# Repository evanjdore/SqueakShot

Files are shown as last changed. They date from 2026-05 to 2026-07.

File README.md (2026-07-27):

<p align="center">
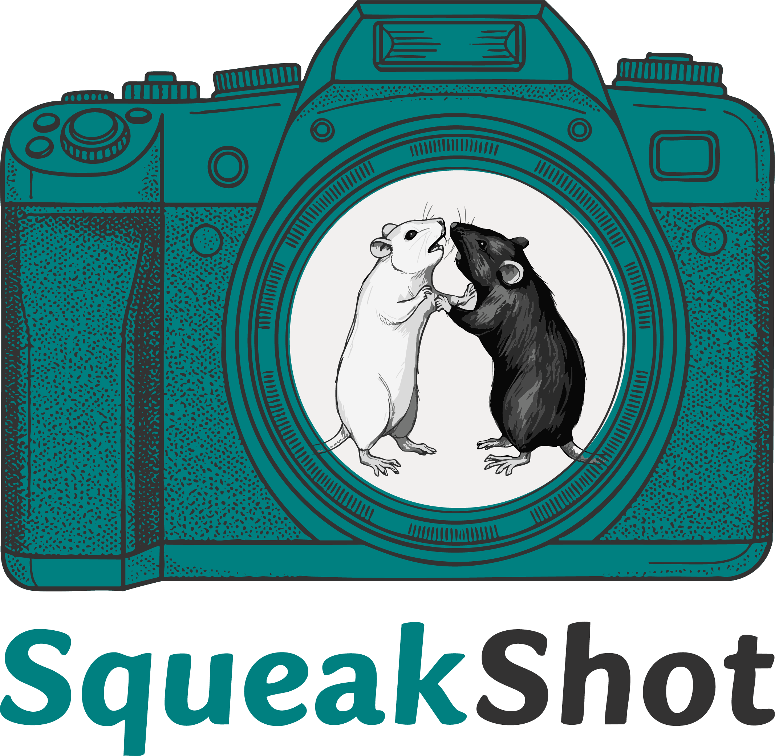
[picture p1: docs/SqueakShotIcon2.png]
SqueakShot
  
</p>

# SqueakShot

Synchronized multi-camera video recording for the Raspberry Pi, built for
behavioral neuroscience experiments (rodent vocalization + behavior, hence the
name) where several camera angles of the same animal must line up
frame-for-frame.

A set of Raspberry Pi 4 / 5 units — one *server* plus any number of *clients* —
record H.264 video with per-frame microsecond timestamps, all starting at the
same wall-clock instant. A desktop controller (a small Flask web app, currently
**v9.2.5**) drives the whole workflow from one browser UI: previewing,
recording, pulling footage off the Pis, encoding to MP4, frame-matching the
cameras to each other, and trimming to the behavior window.

## What it does

The full pipeline, all from `http://localhost:5000`:

1. **Record** — Enter an animal ID and project ID and hit *Start Recording*.
   Every Pi opens its encoder at the same scheduled moment (see
   [synchronization](#how-synchronization-works)). Footage lands on each Pi's
   SD card as a `.h264` file plus a `.pts` sidecar of per-frame timestamps.
2. **Preview** — Live MJPEG streams from every camera for framing and focus.
   Mutually exclusive with recording, since the cameras can't be shared.
3. **Encode** — Download the raw footage from every Pi in parallel and encode
   each camera to MP4.
4. **Sync** — Analyze the `.pts` files, match frames across all cameras to
   within a 20 ms tolerance, and write per-camera *synced* MP4s that begin on
   the same frame.
5. **Trim** — Scrub to the start and end of the behavior bout on a frame
   preview, then clip every camera together to that exact range.

Pre-flight checks (clock skew and free disk on each Pi), live thermal and
throttling status per camera, and an in-GUI settings deploy round it out.

## What's new

- **v9.2.5 (current)** — `.pts` sidecars are now written reliably on the Pi 5
  via a `TimestampingFileOutput` subclass, since `picamera2`'s
  `start_encoder(pts=...)` is silently ignored on the libav code path. Also
  ships a runtime monkey-patch for the `picamera2` + PyAV ≥14 incompatibility
  (`pict_type` must be an int, not the string `"I"`) that otherwise crashes
  the encoder on newer images. Quiets the bogus "force_key_frame unsupported"
  log line.
- **v9.2** — Fixes 0-byte `.h264` recordings on the Pi 5, an installer bug
  that deployed only the first camera, and server-side control-socket races.
  Adds `SQUEAKSHOT_PORT` and `SQUEAKSHOT_PREFLIGHT_CLOCK_SKEW_MS` environment
  variables (the former dodges macOS AirPlay on port 5000). Full detail in
  [CHANGELOG.md](CHANGELOG.md).
- **Isolated install** — The desktop controller installs into a conda/mamba
  environment (`environment.yml`) that also bundles FFmpeg, so nothing touches
  your system Python and there is no separate FFmpeg download.
- **Deploy settings from the GUI** — The Settings tab can push camera
  resolution/fps/bitrate to every Pi and restart the record service, instead
  of re-running `install.sh`.
- Inline pre-flight results, per-camera preview reload, parallel encode /
  sync / trim, and assorted bug fixes (see `CHANGELOG.md`).

## Hardware

- Two or more Raspberry Pi 4 / 5 running Raspberry Pi OS Bookworm (64-bit)
- A Camera Module 3 (IMX708, Wide variant recommended) on each Pi
- Wired Ethernet between every Pi and the desktop running the controller
  (Wi-Fi works but degrades preview latency and pre-flight clock-skew margin)
- A desktop (Windows / macOS / Linux) for the controller — modest CPU is fine,
  the heavy lifting is FFmpeg encode/sync on a small number of camera streams

For the reference physical rig — a 3D-printed three-camera enclosure built
around a single mouse cage — see the **[hardware build guide](BUILD.md)**. It
covers the full bill of materials, dimensions, wiring, and assembly, and the
printable `.3mf` / editable `.f3d` files live in [`hardware/`](hardware/).

## Installation

See [INSTALL.md](INSTALL.md) for the full walkthrough. The short version:

### Prerequisites

**On each Raspberry Pi** — Raspberry Pi OS Bookworm (64-bit), a working Camera
Module 3, SSH enabled, and `python3-picamera2` + `python3-av` installed (both
ship on standard Bookworm images). On the Pi 5 specifically, `python3-av` is
not optional — without it the recorder falls back to the V4L2 H.264 path,
which has produced 0-byte `.h264` files on some libcamera builds.

**On the desktop** — conda or mamba (recommended, e.g. via Miniforge). The
controller's Python, Flask, NumPy, and FFmpeg all come from the
`environment.yml` conda environment. Without conda you instead need Python
3.10+ and FFmpeg/FFprobe on `PATH` yourself (the launcher will pip-install
Flask + NumPy in that case).

You also need passwordless SSH from the desktop to every Pi
(`ssh-copy-id user@pi-ip`) and the Pis on NTP / chrony so their wall clocks
agree to within ~100 ms (pre-flight check enforces this).

### 1. Configure

```bash
./setup.sh                   # setup.bat on Windows
```

Interactively asks for each camera's name / IP / SSH user, the video
directories, and the resolution / fps / bitrate, then writes
`controller/camera_config.json`.

### 2. Deploy to the Pis

```bash
cd pi-deploy && ./install.sh
```

Copies the capture scripts and a generated `camera_settings.json` to every Pi,
installs the `squeakshot-record` and `squeakshot-preview` systemd services,
and grants passwordless `systemctl` for just those two units.

### 3. Launch the controller

```bash
cd .. && ./SqueakShot.sh     # SqueakShot.bat on Windows
```

On the first run this builds the `squeakshot` conda environment from
`environment.yml` (a minute or two); later runs reuse it. If conda/mamba is
not found, it falls back to installing Flask + NumPy with `pip`. Then open
<http://localhost:5000>.

To build the environment yourself ahead of time:

```bash
conda env create -f environment.yml      # or: mamba env create -f environment.yml
```

For day-to-day use after install, see [QUICKSTART.md](QUICKSTART.md).

## Architecture

```
                          ┌─────────────────────┐
                          │   Desktop Controller │
                          │  (Flask, port 5000)  │
                          └──────────┬──────────┘
                                     │ TCP 5006 (control)
                                     │ HTTP 8080 (preview)
                                     │ SSH (deploy / systemctl)
                                     ▼
                          ┌──────────────────────┐
                          │  cam0 (server, Pi)   │◄─── records
                          │  port 5005 ─ clients │
                          │  port 5006 ─ control │
                          │  port 8080 ─ preview │
                          └──┬───────────────┬───┘
                             │ TCP 5005      │
                             ▼               ▼
                       ┌──────────┐     ┌──────────┐
                       │   cam1   │     │   cam2   │
                       │  client  │     │  client  │
                       └──────────┘     └──────────┘
```

The controller never talks to client cameras directly: it sends one control
command to the server (cam0), which fans it out to every client. Clients
identify themselves to the server with a `HELLO:<name>` handshake, so cameras
are matched by name rather than connection order.

## How synchronization works

All cameras share a wall-clock reference, so keep the Pis on NTP / chrony. On
*Start Recording* the server schedules a precise start time about 3 seconds in
the future, sends it to every client, waits for ACKs, then everyone busy-waits
to that exact instant before opening their encoder. The `.pts` sidecar next to
each `.h264` records a microsecond timestamp per frame (written by
`TimestampingFileOutput`, a `FileOutput` subclass — `picamera2`'s built-in
`pts=` kwarg is silently ignored on the libav path used by the Pi 5). The
Sync stage uses those timestamps to match frames across cameras offline,
within a 20 ms tolerance.

Heartbeats keep the cluster honest: the server sends `PING` every 10 s during
recording; any client that hears nothing for 30 s auto-stops, so a crashed
server doesn't quietly fill SD cards.

The pre-flight check flags any Pi whose clock is off by more than ~100 ms
(tunable via `SQUEAKSHOT_PREFLIGHT_CLOCK_SKEW_MS`), since skew directly
degrades sync quality.

## Output

- **Raw on Pi**: `~/camera_videos/<camN>_<animal>_<project>.{h264,pts}`
- **Raw pulled to desktop**: `~/SqueakShot_Videos/raw/*.{h264,pts}`
- **Encoded locally**: `~/SqueakShot_Videos/encoded/*.mp4`
- **Synced** (frame-matched across cameras): `~/SqueakShot_Videos/synced/*.mp4`
- **Trimmed** (final clipped clips): `~/SqueakShot_Videos/trimmed/*.mp4`

## Settings that matter

- `output_width` × `output_height`: actual recorded resolution (default 1536×864)
- `sensor_width` × `sensor_height`: leave at 2304×1296 to keep full lens FOV
- `framerate`: 56 fps is the maximum for the binned 2304×1296 sensor mode
  on the IMX708
- `bitrate_mbps`: 25 is plenty for 1536×864; raise for full-res

The ISP downscale trick: the camera reads the same 2304×1296 binned sensor
mode (full FOV) regardless of `output_width`/`output_height`, and the IMX708
ISP scales down before the encoder sees it. So lowering `output_*` reduces
encoder load and bandwidth, but keeps the lens view.

Changing these in the **Settings** tab updates the controller's config; click
**Deploy to Pis** there to copy them to every camera and restart the record
service so they take effect. This is the same operation as re-running
`pi-deploy/install.sh`, but in-place from the GUI.

## Files

```
SqueakShot/
├── SqueakShot.sh / .bat / .command   # launchers
├── setup.sh / .bat                   # interactive config
├── environment.yml                   # conda/mamba env for the controller
├── controller/
│   ├── camera_controller.py          # Flask app
│   ├── sync_lib.py                   # shared N-camera frame-matching algorithm
│   ├── camera_config.example.json    # template config
│   ├── requirements.txt              # pip fallback deps
│   └── templates/controller.html     # web UI
├── pi-deploy/
│   ├── sync_capture.py               # capture service (multi-client server / client)
│   ├── camera_preview.py             # MJPEG preview server
│   ├── install.sh                    # deploys to every camera in config
│   ├── README.md                     # Pi-side files reference + manual deploy notes
│   └── services/
│       ├── squeakshot-record.service.template
│       └── squeakshot-preview.service.template
├── tools/
│   └── sync_videos.py                # standalone offline sync tool (GUI + CLI)
│                                     # — usable without the controller, e.g. for
│                                     # post-hoc resync of older recordings
├── hardware/                         # 3D-print + CAD files for the physical rig
│   ├── print/                        # print-ready .3mf (housing + Pi case)
│   ├── cad/                          # editable Fusion 360 .f3d sources
│   └── README.md                     # hardware file index
├── docs/
│   ├── SqueakShotIcon2.png           # project logo (README header + controller UI)
│   └── images/                       # build-guide renders
├── BUILD.md                          # hardware build guide (BOM, dimensions, assembly)
├── INSTALL.md                        # full installation walkthrough
├── QUICKSTART.md                     # day-to-day usage
├── DEPLOYMENT_HISTORY.md             # field notes
├── CHANGELOG.md
└── README.md
```

## Troubleshooting

**Cameras show as offline.** Check that `ssh user@ip` from your desktop works
without a password (set up keys with `ssh-copy-id`).

**Preview shows "not active".** The record service blocks the camera. Click
"Start Previews" on the Preview tab — it stops the record service first.

**Recording errors with "Clients did not ack".** Check that the
`squeakshot-record` service is running on every client Pi:
```bash
ssh user@cam1 'sudo systemctl status squeakshot-record'
```
If it shows "Permission denied" on systemctl from the controller, re-run
`pi-deploy/install.sh` to set up the passwordless sudo rule.

**Sync quality is "Fair" or worse.** Check whether one camera is dropping
frames (compare per-camera frame counts in the analysis output). Common
causes: under-volted Pi (check thermal cards in Recording tab), CPU
throttling, SD card too slow.

**Settings changes don't take effect.** Editing settings in the GUI only
updates the controller's config. Use **Deploy to Pis** on the Settings tab (or
re-run `pi-deploy/install.sh`) to push them to the cameras.

# Lab
This project was funded by the Maiya Lab at LSUHSC New Orleans

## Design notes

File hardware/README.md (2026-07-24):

# Hardware files

3D-printable parts and CAD sources for the SqueakShot recording rig. For the
full build walkthrough (bill of materials, dimensions, assembly, wiring) see
[../BUILD.md](../BUILD.md).

> **Git LFS:** the `.3mf` and `.f3d` files are tracked with
> [Git LFS](https://git-lfs.com). After cloning, run `git lfs install` once and
> `git lfs pull` to download them.

## Print-ready (`.3mf`)

Print in PLA on the Bambu Lab X1-Carbon (or any FDM printer).

| File | Part |
|---|---|
| `print/recording_housing_parts/LeftSide.3mf` | Housing — left side |
| `print/recording_housing_parts/RightSide.3mf` | Housing — right side |
| `print/recording_housing_parts/LeftStand.3mf` | Housing — left stand |
| `print/recording_housing_parts/RightStand.3mf` | Housing — right stand |
| `print/recording_housing_parts/Lid_Housing.3mf` | Housing — lid |
| `print/raspi_case/Case_Supports.3mf` | Pi case body (with print supports) |
| `print/raspi_case/Lid.3mf` | Pi case lid |
| `print/raspi_case/Buttons.3mf` | Pi case buttons |
| `print/RecordingSetup_3DPrint.3mf` | Combined plate of all parts |

## CAD sources (`.f3d`)

Editable Autodesk Fusion 360 files.

| File | Contents |
|---|---|
| `cad/FullSetup.f3d` | Full assembly (housing + cage + cameras + Pis) |
| `cad/RaspiCase.f3d` | Raspberry Pi case assembly |
| `cad/LeftSide.f3d`, `cad/RightSide.f3d` | Housing side panels |
| `cad/LeftStand.f3d`, `cad/RightStand.f3d` | Housing stands |
| `cad/Lid_Recording.f3d` | Housing lid |
| `cad/raspi_case/Case_with_Supports.f3d` | Pi case body |
| `cad/raspi_case/Lid.f3d` | Pi case lid |
| `cad/raspi_case/Buttons.f3d` | Pi case buttons |

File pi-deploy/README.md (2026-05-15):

# pi-deploy

Files that get pushed to each Raspberry Pi.

## Files

| File | Purpose |
|---|---|
| `sync_capture.py` | Main capture service. Server mode for cam0, client mode for cam1+. |
| `camera_preview.py` | MJPEG preview server (port 8080). Mutually exclusive with sync_capture. |
| `services/squeakshot-record.service.template` | systemd unit for the record service. `install.sh` fills in `__USER__` and `__EXEC__`. |
| `services/squeakshot-preview.service.template` | systemd unit for preview. |
| `install.sh` | Deploys everything to all cameras in `../controller/camera_config.json`. |

## How `install.sh` works

For each camera in the config:
1. SCP `sync_capture.py`, `camera_preview.py`, and a Pi-side
   `camera_settings.json` (derived from the controller config's
   `camera_settings` section) to `/home/<user>/`.
2. Substitute placeholders into the service templates:
   - Server: `python3 sync_capture.py server --config ~/camera_settings.json`
   - Client: `python3 sync_capture.py client --server-ip <IP> --name <NAME> --config ~/camera_settings.json`
3. Install both unit files to `/etc/systemd/system/`, reload daemon, enable
   `squeakshot-record` (auto-start on boot). Preview is manual-start only.
4. Drop a sudoers file allowing the user to `sudo systemctl start/stop`
   those two units without a password (the controller calls this over SSH).

The two services declare `Conflicts=` against each other, so starting one
stops the other automatically.

## Manual deployment (advanced)

If `install.sh` doesn't fit your environment, the equivalent manual steps
on one Pi:

```bash
# On the desktop:
scp pi-deploy/sync_capture.py   maiya@cam0:/home/maiya/
scp pi-deploy/camera_preview.py maiya@cam0:/home/maiya/

# Create camera_settings.json on the Pi:
ssh maiya@cam0 'cat > ~/camera_settings.json' <<'EOF'
{
  "output_width": 1536,
  "output_height": 864,
  "sensor_width": 2304,
  "sensor_height": 1296,
  "framerate": 56,
  "bitrate_mbps": 25,
  "video_dir": "/home/maiya/camera_videos"
}
EOF

# Run sync_capture by hand to test:
ssh maiya@cam0 'python3 ~/sync_capture.py server'   # on cam0
ssh maiya@cam1 'python3 ~/sync_capture.py client --server-ip <CAM0-IP> --name cam1'
```

## Settings file (`camera_settings.json` on each Pi)

```json
{
  "output_width": 1536,    // ISP output resolution width
  "output_height": 864,    // ISP output resolution height
  "sensor_width": 2304,    // sensor mode width (preserves FOV)
  "sensor_height": 1296,   // sensor mode height
  "framerate": 56,         // locked framerate (FrameDurationLimits)
  "bitrate_mbps": 25,      // H.264 bitrate
  "video_dir": "/home/maiya/camera_videos"
}
```

The sensor mode at 2304×1296 is the full-FOV 2×2-binned mode for the IMX708
(Camera Module 3). Lowering `output_*` reduces encoder load and bandwidth
without affecting the lens field of view.

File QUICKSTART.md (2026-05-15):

# Quick Start

Daily use, assuming everything is installed and configured.

## Recording

1. Power on all Pis. The `squeakshot-record` service starts automatically.
2. Launch the controller: `./SqueakShot.sh` (or `SqueakShot.bat`).
3. Open <http://localhost:5000>.
4. Make sure all cameras show **Online**.
5. Recording tab → enter Animal ID and Project ID → **Start Recording**.
6. **Stop Recording** when done.

## Post-processing

After a session, on the Encode tab:

1. Select your recording from the dropdown.
2. **Download from Pis**.
3. Once downloaded, select it under Step 2 and click **Start Encoding**.
4. Switch to the Sync tab, select the same recording, click **Analyze**.
   If sync quality is Good or Excellent, click **Start Synchronization**.
5. Switch to the Trim tab if you want to clip the behavior window.

## Preview (no recording)

Preview tab → **Start Previews** → live MJPEG from each Pi.

To go back to recording: **Stop Previews** → Recording tab → record as normal.

## Files

Default locations on the controller:

```
~/SqueakShot_Videos/
├── raw/        # H.264 + PTS pulled from Pis
├── encoded/    # MP4 + PTS
├── synced/     # frame-matched MP4s
└── trimmed/    # final clipped MP4s
```

On each Pi:

```
~/camera_videos/<camN>_<animal>_<project>.h264
~/camera_videos/<camN>_<animal>_<project>.pts
```

## Common commands

Check service status on a Pi:
```bash
ssh maiya@<cam-ip> 'sudo systemctl status squeakshot-record'
```

Tail logs on a Pi:
```bash
ssh maiya@<cam-ip> 'journalctl -u squeakshot-record -f'
```

Restart a Pi service from the desktop:
```bash
ssh maiya@<cam-ip> 'sudo systemctl restart squeakshot-record'
```

Run the standalone offline sync tool:
```bash
python tools/sync_videos.py
```

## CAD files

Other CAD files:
hardware/print/raspi_case/Lid.3mf
hardware/print/recording_housing_parts/LeftStand.3mf
hardware/print/RecordingSetup_3DPrint.3mf
hardware/print/raspi_case/Buttons.3mf
hardware/print/recording_housing_parts/Lid_Housing.3mf
hardware/print/raspi_case/Case_Supports.3mf
hardware/print/recording_housing_parts/LeftSide.3mf
hardware/print/recording_housing_parts/RightStand.3mf
hardware/print/recording_housing_parts/RightSide.3mf
hardware/cad/FullSetup.f3d
hardware/cad/LeftSide.f3d
hardware/cad/LeftStand.f3d
hardware/cad/Lid_Recording.f3d
hardware/cad/RaspiCase.f3d
hardware/cad/RightSide.f3d
hardware/cad/RightStand.f3d
hardware/cad/raspi_case/Buttons.f3d
hardware/cad/raspi_case/Case_with_Supports.f3d
hardware/cad/raspi_case/Lid.f3d

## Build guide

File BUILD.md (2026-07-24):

# Hardware Build Guide

How to build the physical SqueakShot recording rig: a custom three-camera,
calibrated and synchronized enclosure that seats a single mouse home cage and
films it from three synchronized overhead cameras. This document covers the
bill of materials, dimensions, 3D-printed parts, assembly, and wiring. For the
software install and day-to-day operation, see [INSTALL.md](INSTALL.md) and
[QUICKSTART.md](QUICKSTART.md).

<p align="center">
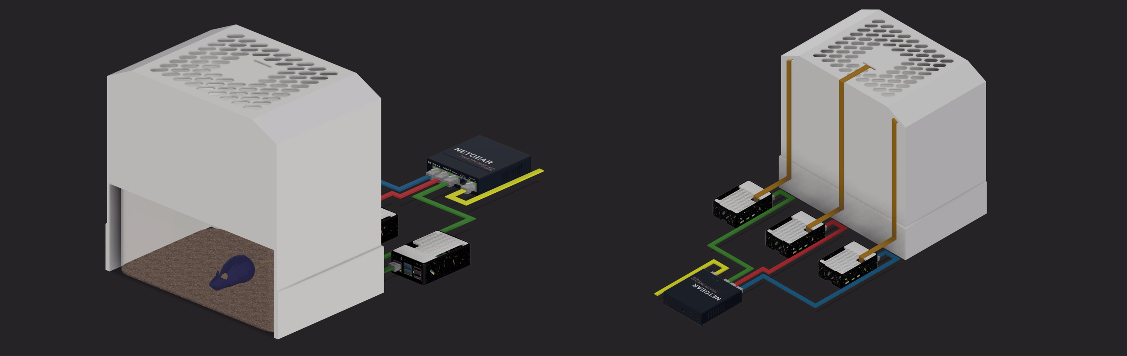
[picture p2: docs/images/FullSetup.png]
The full SqueakShot recording setup
  
</p>

The 3D-printed housing seats a single home cage (mouse shown on bedding at
left) while three overhead cameras look down into the arena. Each camera's
Raspberry Pi, in its own printed case, connects by Ethernet to a network
switch. The right-hand view shows the camera routing to the top of the housing.

## Bill of materials

The reference build uses three cameras (one server + two clients). Quantities
scale by the number of cameras.

### Compute and acquisition

| Qty | Item |
|:---:|---|
| 3 | Raspberry Pi 5 (8 GB) |
| 3 | Raspberry Pi 5 Official Active Cooler |
| 3 | Raspberry Pi 5 power supply |
| 3 | Raspberry Pi M.2 HAT+ |
| 3 | Raspberry Pi NVMe SSD (256 GB) |

### Cameras and optics

| Qty | Item |
|:---:|---|
| 3 | Raspberry Pi Camera Module 3 Wide NoIR (Sony IMX708, wide FOV; IR-cut filter omitted for recording under dim red light) |
| 3 | Official CSI FPC flexible cable, 22-pin to 15-pin, 500 mm (Raspberry Pi 5 compatible) |

### Networking and synchronization

| Qty | Item |
|:---:|---|
| 1 | Network switch (5-port Gigabit unmanaged Ethernet) |
| 3 | Ethernet cables |
| 3 | Real-time clock (RTC) module (one per Raspberry Pi, for hardware timekeeping) |

### Enclosure and fabrication

| Qty | Item |
|:---:|---|
| 1 | Bambu Lab X1-Carbon 3D printer |
| — | Black and white PLA filament |
| 1 | 860-pc M2–M5 12.9 alloy-steel hex bolt & nut kit (with lock and flat washers + wrench) |
| — | Superglue |
| — | White lab tape |

### Peripherals

| Qty | Item |
|:---:|---|
| 1 | Monitor |
| 1 | Raspberry Pi micro-HDMI to HDMI cable |

## Dimensions

The housing is purpose-built around one specific cage (Allentown PC75JHT), so
the cameras hold a fixed, calibrated geometry relative to the arena floor.

| Component | Depth | Width | Height |
|---|---|---|---|
| 3D-printed recording housing | 200 mm | 210 mm | 306.5 mm |
| Allentown PC75JHT mouse cage | 186 mm (7.5 in) | 298 mm (11.75 in) | 128 mm (5 in) |

Cage floor area: 75 sq in (484 cm²).

## 3D-printed parts

All parts print in PLA on the Bambu Lab X1-Carbon. Print-ready `.3mf` files and
the editable Fusion 360 `.f3d` sources are in [`hardware/`](hardware/) — see
[`hardware/README.md`](hardware/README.md) for the full file index.

> **Note:** the `.f3d` / `.3mf` files are stored with [Git LFS](https://git-lfs.com).
> After cloning, run `git lfs pull` to download them (or download individually
> from the GitHub file browser).

### Recording housing

Five printed parts make up the enclosure that holds the cameras over the cage:
`LeftSide`, `RightSide`, `LeftStand`, `RightStand`, and `Lid_Housing`
(`hardware/print/recording_housing_parts/`).

> **Note:** add print settings (filament colors, layer height, supports, and
> approximate print time).

### Raspberry Pi case

Each Pi is built into its own printed case. The exploded view labels the
3D-printed parts (A, F) and the Raspberry Pi parts (B–E):

<p align="center">
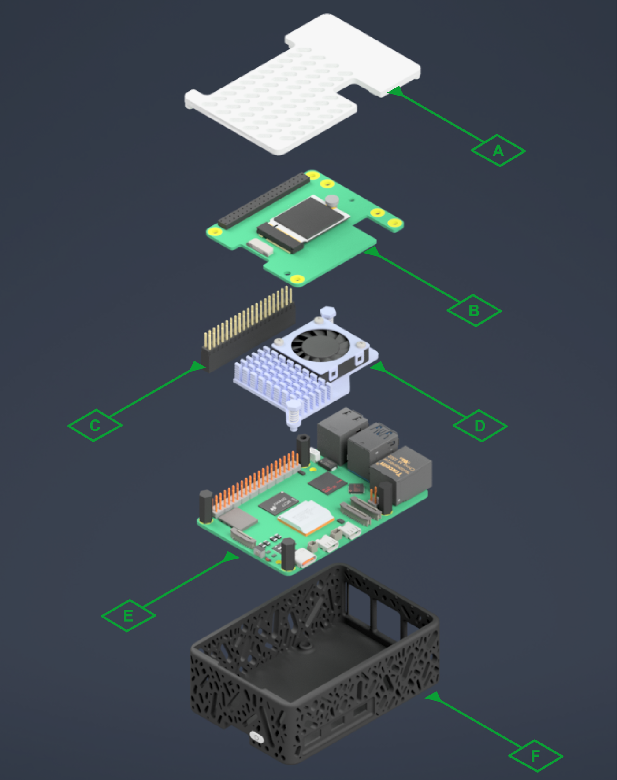
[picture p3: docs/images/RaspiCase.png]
Exploded view of the Raspberry Pi case
  
  &nbsp;&nbsp;
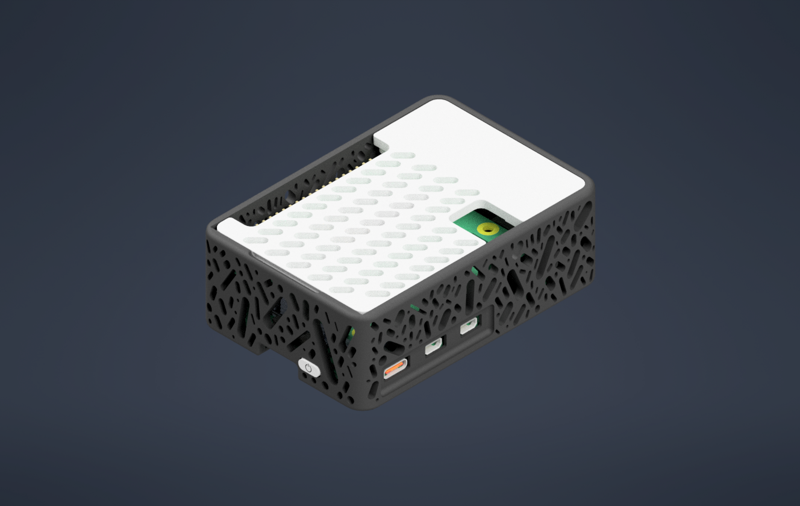
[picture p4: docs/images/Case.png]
The assembled Raspberry Pi case
  
</p>

| Label | Part |
|:-----:|---|
| A | 3D-printed lid |
| B | M.2 HAT+ with NVMe SSD |
| C | Stacking GPIO header |
| D | Active Cooler |
| E | Raspberry Pi 5 |
| F | 3D-printed case body |

Printed parts: `Case_Supports`, `Lid`, `Buttons`
(`hardware/print/raspi_case/`).

## Assembly

1. **Print the parts.** Print the recording-housing parts and one Pi case per
   camera in PLA (files in [`hardware/print/`](hardware/print)).
2. **Build each Pi case.** Seat the Raspberry Pi 5 (E) in the case body (F).
   Add the Active Cooler (D) and a stacking GPIO header (C), then the M.2 HAT+
   carrying the NVMe SSD (B). Close with the vented lid (A).
3. **Mount cameras and Pis in the housing.** Fix each Camera Module 3 Wide NoIR
   at its overhead position and route its 500 mm CSI cable to its Pi. Use
   hardware from the M2–M5 kit; superglue where noted.
4. **Seat the cage.** Place the Allentown PC75JHT cage into the housing so the
   floor sits at the calibrated working distance.

> **Note:** add camera angle / mounting detail, which fasteners vs. superglue
> are used where, and any alignment marks for repeatable cage placement.

## Wiring & network

All three Raspberry Pi units connect by Ethernet to the network switch, forming
an isolated local network for footage transfer and clock synchronization. Each
Pi carries its own RTC module for hardware timekeeping between NTP syncs, and
each camera connects to its Pi over the 22-pin-to-15-pin CSI ribbon cable.

| Link | From | To |
|---|---|----|
| Data / sync | Each Raspberry Pi (×3) | Network switch (Ethernet) |
| Camera | Camera Module 3 Wide NoIR (×3) | Its Raspberry Pi (CSI, 500 mm) |
| Timekeeping | RTC module (×3) | Its Raspberry Pi (GPIO / I²C) |
| Power | Official Pi 5 supply (×3) | Its Raspberry Pi |

Keep the Pis on NTP / chrony so their wall clocks agree to within ~100 ms; the
controller's pre-flight check enforces this. See
[How synchronization works](README.md#how-synchronization-works) for detail.

## Next: software

With the rig assembled and networked, install and run the controller:

- [INSTALL.md](INSTALL.md) — full software installation walkthrough
- [QUICKSTART.md](QUICKSTART.md) — day-to-day recording and post-processing

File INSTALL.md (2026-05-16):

# Installation Guide

This guide walks through setting up SqueakShot v9.1 from scratch on three Pis
plus a desktop controller.

## Prerequisites

### On every Raspberry Pi

- Raspberry Pi OS Bookworm (64-bit) with a working Camera Module 3
- A static or DHCP-reserved IP on the same network as the desktop
- Python 3.10+ with `picamera2` installed (default on Bookworm)
- SSH server enabled (`sudo raspi-config` → Interface Options → SSH)

Test the camera works at all:
```bash
libcamera-still -o test.jpg
```

Create the video directory:
```bash
mkdir -p ~/camera_videos
```

### On the desktop controller

- An SSH client that can reach each Pi by IP
- SSH key set up to each Pi (`ssh-copy-id user@cam0-ip`, etc.)
- **Recommended:** conda or mamba installed (e.g. via Miniforge). The
  controller's Python, Flask, NumPy, and FFmpeg/FFprobe all come from an
  isolated conda environment defined in `environment.yml`, so nothing
  pollutes your system Python and there is no separate FFmpeg install.
- **Without conda:** Python 3.10+ on PATH, plus FFmpeg/FFprobe installed
  yourself — `brew install ffmpeg` on macOS, or static builds from
  ffmpeg.org added to `Path` on Windows. In this fallback case the launcher
  pip-installs Flask + NumPy into the current Python.

## Step 1: Run setup

From the top of the SqueakShot folder:
```bash
./setup.sh         # macOS / Linux
setup.bat          # Windows
```

It will ask:
- How many cameras (default 3)
- The IP, username, and name of each one. The first camera is always the
  server; the rest are clients.
- The remote video dir on the Pis (default `/home/<user>/camera_videos`)
- The local output dir on the desktop (default `~/SqueakShot_Videos`)
- Camera resolution, framerate, bitrate (defaults: 1536×864 @ 56 fps, 25 Mbps)

This writes `controller/camera_config.json`.

## Step 2: Verify SSH keys

For each Pi listed in the config:
```bash
ssh maiya@<cam-ip> 'echo OK'
```
If you get a password prompt, run `ssh-copy-id maiya@<cam-ip>` first.

The first SSH connection asks about host fingerprints; accept them or
pre-seed `~/.ssh/known_hosts`.

## Step 3: Deploy capture services to Pis

From the SqueakShot folder:
```bash
cd pi-deploy
./install.sh
```

This loops through every camera in your config and:
1. SCPs `sync_capture.py`, `camera_preview.py`, and a `camera_settings.json`
2. Installs `squeakshot-record.service` and `squeakshot-preview.service`
3. Enables `squeakshot-record` to auto-start on boot
4. Sets up a sudoers rule so the user can `sudo systemctl start/stop` those
   two units without a password (the controller needs this to manage
   services over SSH)

Reboot each Pi, or start the service manually:
```bash
ssh maiya@<cam-ip> 'sudo systemctl start squeakshot-record'
```

## Step 4: Launch the controller

```bash
./SqueakShot.sh          # macOS / Linux
SqueakShot.bat           # Windows
```

On the first launch, if conda or mamba is available the launcher creates an
isolated `squeakshot` environment from `environment.yml` (Python, Flask,
NumPy, FFmpeg) — expect a minute or two. Subsequent launches reuse it. If
conda/mamba is not found, it falls back to pip-installing Flask + NumPy into
the current Python.

To create the environment yourself ahead of time instead:
```bash
conda env create -f environment.yml     # or: mamba env create -f environment.yml
```

Open <http://localhost:5000>.

You should see one status card per camera. If they all show "Online" with
sensible thermal readings, you are good to go.

## Step 5: First recording

1. **Recording tab.** Enter an Animal ID and Project ID (e.g. `Mouse001`,
   `Test01`).
2. Click **Start Recording**. Within a few seconds, all cameras should show
   recording in their per-camera status. The big timer counts up.
3. Click **Stop Recording**. Files land at
   `/home/<user>/camera_videos/<camN>_Mouse001_Test01.h264` (and `.pts`) on
   every Pi.

## Step 6: Encode / Sync / Trim

These run on the desktop, not the Pis.

1. **Encode tab.** Select your recording → **Download from Pis** → after the
   download finishes select it under "Step 2: Encode to MP4" → **Start
   Encoding**.
2. **Sync tab.** Select the encoded recording → **Analyze** to see frame
   counts, matched frames, and quality → **Start Synchronization** to trim
   each camera to the matched window.
3. **Trim tab.** Select a synced recording → scrub to the start and end of
   the behavior bout you care about → **Trim Videos**.

## Step 7: Preview mode

1. **Preview tab.** Click **Start Previews**. The record service stops on
   every Pi, and each Pi spins up an MJPEG server on port 8080. The
   `<img>` tags in the GUI stream live video.
2. Click **Stop Previews** when done. To resume recording, click **Start
   Services** on the Recording tab (or just hit Start Recording, it
   auto-starts the services).

## Troubleshooting

### Camera shows offline after install

```bash
ssh maiya@<cam-ip>
sudo systemctl status squeakshot-record
journalctl -u squeakshot-record -n 50 --no-pager
```

Common causes:
- `picamera2` not installed (`sudo apt install python3-picamera2`)
- Another process owns the camera (`sudo fuser /dev/video*`)
- The settings file is missing or malformed (`cat ~/camera_settings.json`)

### Sync quality is "Fair"

The matching tolerance is 20 ms. Anything worse means frames are dropping
on at least one camera. Look at the per-camera frame counts in the analyze
output. The most common cause is a thermally throttled Pi, check the
thermal cards on the Recording tab.

### Preview doesn't show video

The browser may be blocked from cross-origin requests if you change ports.
The MJPEG server sends `Access-Control-Allow-Origin: *`, so plain `<img>`
embedding should work. If you only see the placeholder, verify:
```bash
ssh maiya@<cam-ip> 'sudo systemctl status squeakshot-preview'
```
and try `curl http://<cam-ip>:8080/status` from the desktop.

### "Already recording" or weird state

Click **Stop Services** on the Recording tab. If that fails:
```bash
ssh maiya@<cam-ip> 'sudo systemctl stop squeakshot-record squeakshot-preview'
```
Then click **Start Services** to come back up cleanly.

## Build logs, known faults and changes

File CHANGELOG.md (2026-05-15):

# Changelog

## v9.2: Pi 5 recording fixes, deployment fixes, Mac compatibility

This release fixes a critical bug where Pi 5 cameras would create `.h264` files
that were 0 bytes (no data written), plus a stdin bug in the installer that
caused only the first camera to receive updates.

Re-run `pi-deploy/install.sh` to push the new Pi-side service to every camera,
and verify python3-av is installed on each Pi (`sudo apt install python3-av`).
Both sides must update together (the controller's server-deadlock fix lives in
sync_capture.py, not in the controller).

### Critical bug fixes

- **Empty .h264 recordings on Pi 5.** Two interacting causes:
  1. `PTSOutput.outputframe` was calling `FileOutput.outputframe`, which has a
     "first frame must be a keyframe" gate. On some Pi 5 libcamera builds this
     check dropped every NAL unit, producing a 0-byte file. `PTSOutput` now
     calls `FileOutput._write` directly to bypass the gate.
  2. The V4L2 `H264Encoder` on Pi 5 can hand the encoder pipeline zero-length
     buffers. New `create_h264_encoder()` prefers `LibavH264Encoder` (software
     x264 via PyAV) when `python3-av` is installed, with the V4L2 encoder as
     a fallback. `iperiod` is set from FPS, `framerate` is passed as
     `fractions.Fraction` (not float, which broke PyAV with
     "'float' object has no attribute 'numerator'"), and `force_key_frame()` is
     nudged after `start_encoder` to make the first NAL an IDR.

- **install.sh deployed only the first camera.** The `while read` loop reads
  from `cameras.tsv`; every `ssh` call inside the loop inherited that stdin and
  consumed the remaining lines. All `ssh` calls inside the loop now use
  `ssh -n` (stdin from `/dev/null`).

- **NoiseReductionModeEnum missing on newer libcamera.** Setting the control
  unconditionally crashed camera setup on some Pi 5 builds. Now guarded with
  `getattr(controls, "NoiseReductionModeEnum", None)`.

- **encode="main" explicit.** `create_video_configuration` now explicitly
  targets the main YUV stream for H264 encoding instead of relying on the
  default, which has varied across picamera2 versions.

### Server deadlock and control socket races

- **Worker thread for control commands.** The server's main `select()` loop
  used to call `_handle_control_command` directly, blocking Picamera2 servicing
  during `wait_until` and `start_encoder`. Commands now run on a dedicated
  daemon worker thread fed by a queue.
- **`control_busy` Event.** While the worker is processing a command (and
  possibly sending `OK:`/`ERROR:`), the main `select()` loop omits the control
  socket from the read list. This eliminates `[Errno 9] Bad file descriptor`
  and other races where the main thread `recv()`'d concurrently with the
  worker's `send()`.
- **`control_holder` dict.** Replaces a stale `control_conn` local that could
  point at a closed socket when the worker reconnected the controller.
- **Initial STATUS send is blocking.** `_accept_controller` flips the new
  socket to blocking just long enough to send the initial `STATUS:` line, then
  back to non-blocking. Prevents `BlockingIOError` on `sendall` immediately
  after `accept()`.
- **`recv_message` timeout 0.1s -> 5.0s** on control reads. The old value was
  too tight under lab Wi-Fi / SSH muxing.

### Controller (workstation side)

- **`SQUEAKSHOT_PORT` env var** (default 5000) for the Flask UI. Set to
  something else if macOS AirPlay receiver is enabled on port 5000.
- **`SQUEAKSHOT_PREFLIGHT_CLOCK_SKEW_MS` env var** (clamped 50..2000, default
  100). Lets you relax the threshold when controller-vs-Pi skew is stable but
  just over 100 ms.
- **60s wait for cam0:5006** after `systemctl start squeakshot-record`, with
  "Still waiting..." log lines every 10 s. Cold-start camera init plus first
  Libav encoder load can take 30s+.
- **60s timeout on START reply** (was 15s). First Libav startup is slow.
- **Encode pipeline:** skip 0-byte `.h264` with a clear journalctl hint instead
  of opaque ffmpeg error. `ffmpeg -hide_banner -loglevel error`. Failure log
  shows last 1500 chars of stderr.
- **Dedup `ERROR: ERROR:`** when server reply already starts with `ERROR:`.

### Operational notes

- **`python3-av` required on Pis** for the preferred Libav encoder path.
  Already present on standard Raspberry Pi OS images. If missing:
  `sudo apt install python3-av`. Falls back to V4L2 encoder with a log warning
  if unavailable.
- See `DEPLOYMENT_HISTORY.md` for IPs, install flow, Mac sntp path, Chrony vs
  `timedatectl`, and other field notes.

## v9.1: Bug fixes, pre-flight checks, parallel pipeline

No breaking config changes. Re-run `pi-deploy/install.sh` to push the updated
`sync_capture.py` and refreshed sudoers rule to every Pi. Controller will use
the new wire format automatically; Pis on v9.0 `sync_capture.py` will reject
the new `START:name=fn:...` format, so both sides must update together.

### Bug fixes

- **Renamed cameras now work.** The `START` command from controller to server
  now carries `name=filename` pairs instead of positional ordering. The server
  matches clients by name in the `clients` dict, so renaming a camera in the
  settings UI no longer breaks recording start.
- **Sudoers rule covers both systemctl paths.** Bookworm sudo may resolve
  `systemctl` to either `/bin/systemctl` or `/usr/bin/systemctl`. The installer
  now writes both variants so service start/stop works regardless.
- **Sync warns on frame-count discrepancy.** The matching algorithm still clips
  to the shortest camera (it has to), but the analyze step now reports a
  warning when one camera has noticeably fewer frames than the others, so
  silent data loss is visible.
- **Robust file listing.** Recordings list switched from `ls -lh` parsing to
  `find -printf` so filenames with unusual characters don't break the parser.

### Robustness

- **Pre-flight check before recording.** Each Pi is queried for clock skew
  (vs. controller) and free disk space in the video directory. Recording is
  blocked with a 409 if any Pi has a clock off by >100 ms or less than 30 GB
  free; the user can override with a "Record anyway" confirmation. A new
  Pre-flight Check button runs the same check on demand.
- **Heartbeat from server to clients.** Server sends `PING` every 10 s during
  the recording loop. If a client doesn't hear from the server for 30 s
  (server crashed, network died), it auto-stops its own recording instead of
  filling the SD card.
- **Recordings list is now parallel.** One SSH call per camera, run in
  parallel via ThreadPoolExecutor. With 3 cameras and 30 recordings, this
  drops from ~90 SSH calls to 3.
- **Parallel encode / sync / trim.** All three stages now process cameras in
  parallel instead of serial. With 3 cameras this is roughly a 3× wall-clock
  speedup on the workstation.

### Architecture

- **Matching algorithm moved to `controller/sync_lib.py`.** Both the controller
  and `tools/sync_videos.py` now import from there; the duplicated copy in
  `sync_videos.py` is gone. New `analyze_frame_counts()` helper backs the
  discrepancy warning.
- **`preview_running` reflects ground truth.** The status flag is now derived
  from the actual port 8080 probe results across cameras, not a local flag.
  If someone starts the preview service on a Pi manually, the UI sees it.
- **Atomic config save with backup.** `camera_config.json` is now written via
  temp file + `os.replace()`, with `.bak` of the previous version preserved.
  Interrupted saves no longer corrupt the file.
- **Persistent rotating log.** Controller now writes to
  `controller/logs/controller.log` (2 MB × 5 files rotating). The in-memory
  log behavior is unchanged.

### UI

- **Trim frame counters update on direct input.** Typing a number into the
  start/end frame fields refreshes the "Selected: N frames" counter
  immediately, not just when you click Set.

### Intentionally skipped

- No auth on the controller / server. Lab network is trusted; revisit if you
  ever expose this to the broader campus VLAN.
- `install.sh` always overwrites the Pi-side `camera_settings.json`. That file
  is derived from the main `camera_config.json`, so manual edits on the Pi
  are by design clobbered when you re-run the installer. Edit the main config
  and re-install.

---

## v9.0: Multi-camera star topology + ISP downscale + clean pipeline

### Breaking changes

**Config schema.** The old flat keys (`cam0_ip`, `cam1_ip`, `cam0_user`, ...) are
gone. The new format uses a `cameras[]` array. Existing configs are
auto-migrated on first load by the controller, so no manual action is required
unless you wrote scripts that read the JSON directly.

Old:
```json
{
  "cam0_ip": "1.2.3.4",
  "cam1_ip": "1.2.3.5",
  "cam0_user": "maiya",
  "camera_settings": {"width": 2304, "height": 1296, "bitrate": 25}
}
```

New:
```json
{
  "cameras": [
    {"name": "cam0", "ip": "1.2.3.4", "user": "maiya", "role": "server"},
    {"name": "cam1", "ip": "1.2.3.5", "user": "maiya", "role": "client"},
    {"name": "cam2", "ip": "1.2.3.6", "user": "maiya", "role": "client"}
  ],
  "camera_settings": {
    "output_width": 1536,
    "output_height": 864,
    "sensor_width": 2304,
    "sensor_height": 1296,
    "bitrate_mbps": 25,
    "framerate": 56
  }
}
```

**Service control.** Pi-side services are now managed via `systemctl` rather
than SSH-ing in and running `nohup ... & disown`. Re-running `pi-deploy/install.sh`
installs `squeakshot-record.service` and `squeakshot-preview.service` on each
Pi and grants the user passwordless sudo for `systemctl start/stop` on those
two units only.

**sync_capture.py CLI.** Client mode now requires `--name`:
```
# old
python3 sync_capture.py client --server-ip 1.2.3.4

# new
python3 sync_capture.py client --server-ip 1.2.3.4 --name cam1
```

### New features

- **Third camera (and more).** Server (cam0) accepts N clients (cam1, cam2, ...).
  Clients identify themselves with a `HELLO:<name>` handshake on connect.
- **ISP downscaling with FOV preservation.** Output resolution defaults to
  1536×864 while the sensor mode stays at 2304×1296. The ISP scales the binned
  sensor stream down before encoding. Result: same field of view, ~55% fewer
  pixels through the encoder, lower bandwidth, lower Pi load.
- **Preview tab.** Camera previews are now visible in the controller GUI.
  Click "Start Previews" on the Preview tab to spin up the MJPEG streams on
  all Pis. The record service is automatically stopped first (the camera
  cannot be shared). Click "Start Recording" to swap back.
- **Per-camera status everywhere.** Recording status, thermal status, and
  recordings list all dynamically render one card per camera based on the
  current config.

### Cleanup

Files removed:
- `tools/encode.py` (dead MJPEG code from a previous pipeline)
- `controller/diagnose.sh` (hardcoded IPs)
- `controller/fix_previews.sh` (hardcoded IPs)
- `controller/camera_preview.py` (duplicate of `pi-deploy/camera_preview.py`)
- `controller/start.sh`, `controller/start_windows.bat`,
  `controller/start_miniforge.bat` (redundant launchers, use the top-level
  `SqueakShot.sh` / `SqueakShot.bat` / `SqueakShot.command`)
- `pi-deploy/services/squeakshot-server.service` and
  `pi-deploy/services/squeakshot-client.service` (replaced by a single
  templated `squeakshot-record.service.template`)

Two parallel sync algorithms collapsed into one. The matching function in
`tools/sync_videos.py` is now the canonical implementation; the controller
calls the same logic.

### Migration

For an existing 2-camera setup:
1. Pull the new repo or unzip on top of the old one.
2. Run `./setup.sh` (or `setup.bat`) and re-enter your camera info. Or just
   launch the controller, it auto-migrates the old config.
3. Re-run `pi-deploy/install.sh` to push the new sync_capture.py and install
   the systemd units.
4. Reboot the Pis (or run `sudo systemctl start squeakshot-record` on each).

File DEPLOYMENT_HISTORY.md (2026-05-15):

# SqueakShot Deployment History

Field notes from setting up SqueakShot on the lab Pi 5 cluster. Keep here so the
context is not lost between sessions or machines. Update when you discover
something operationally useful.

---

## Hardware / network

Three Raspberry Pi 5 units with Camera Module 3 (IMX708), running Raspberry Pi
OS Bookworm. All three on the lab Wi-Fi / wired LAN.

Default IPs (update if reassigned):

| Camera | Role | IP |
|---|---|---|
| cam0 | server | 155.58.221.8 |
| cam1 | client | 155.58.221.7 |
| cam2 | client | 155.58.221.9 |

SSH user on every Pi: `maiya`. Public key from the controller workstation is in
each Pi's `~/.ssh/authorized_keys`. If a new workstation needs access, run
`ssh-copy-id maiya@<ip>` from it first.

---

## Standard deploy + restart loop

After editing any Pi-side file (`sync_capture.py`, `camera_preview.py`,
`camera_settings.json` content via `camera_config.json`):

```bash
cd pi-deploy && ./install.sh && \
for ip in 155.58.221.8 155.58.221.7 155.58.221.9; do
  ssh -n maiya@$ip 'sudo systemctl restart squeakshot-record'
done
```

The `ssh -n` is important: without it, ssh inherits the stdin of the surrounding
`for` loop and can swallow subsequent iterations. Same reason `install.sh` uses
`ssh -n` internally.

---

## python3-av on the Pis

Required for `LibavH264Encoder` (the preferred software x264 path; avoids the
V4L2 0-byte-file issue on Pi 5). Already present on the lab Pi images. If a new
image is missing it:

```bash
ssh -n maiya@<pi_ip> 'sudo apt install -y python3-av'
```

Verify:

```bash
ssh -n maiya@<pi_ip> 'python3 -c "import av; print(av.__version__)"'
```

If `python3-av` is not installed, `sync_capture.py` falls back to the V4L2
`H264Encoder` and prints a warning at recording start. The fallback works on
many Pi 5 setups but has produced 0-byte `.h264` on others.

---

## Flask port (controller side)

Default is **5000**. On macOS, AirPlay Receiver can claim port 5000 (System
Settings -> General -> AirDrop & Handoff -> AirPlay Receiver). Either turn it
off or:

```bash
export SQUEAKSHOT_PORT=5050
./SqueakShot.sh
```

The launcher prints the chosen port on startup. Open the printed URL.

---

## Control port (Pi side)

cam0's `sync_capture.py` listens on **5006** for the controller. If the
controller logs "could not reach control port" for more than 60 s, check on the
Pi:

```bash
ssh -n maiya@<cam0_ip> 'sudo journalctl -u squeakshot-record -n 80 --no-pager'
```

Common causes:

- python3-av missing AND V4L2 encoder failing -> service exits during
  `start_encoder`.
- Camera Module ribbon not seated -> "no cameras available".
- NoiseReductionModeEnum import error on a fresh libcamera -> guarded as of
  v9.2.

---

## Clock skew

Pre-flight measures clock skew per Pi by capturing controller time, SSHing to
the Pi to capture its time, capturing controller time again, and computing the
midpoint. Default warning threshold: 100 ms.

Identical skew on all cams (say +120 ms on every Pi) almost always means the
**controller's clock** is off relative to the Pis, not the other way around.
Pis run chrony out of the box; Macs sometimes drift if AirPort/Wi-Fi flaps.

To check Pi time sync:

```bash
ssh -n maiya@<pi_ip> 'timedatectl' \
  && ssh -n maiya@<pi_ip> 'chronyc tracking 2>/dev/null || systemctl status systemd-timesyncd'
```

On macOS, install `sntp` via Homebrew if needed (it is in the same formula as
ntpd/chrony tooling on some systems; otherwise use the GNU `chrony` package):

```bash
brew install chrony   # provides chronyc and sntp-like client tools
# or compare directly:
date -u
ssh -n maiya@<cam0_ip> 'date -u'
```

If skew is consistent across all Pis and within ~150 ms, raise the threshold
rather than chasing it:

```bash
export SQUEAKSHOT_PREFLIGHT_CLOCK_SKEW_MS=200
```

---

## Cold-start timing budget

On a power-on of all three Pis, the first recording start can take ~45 s end to
end:

| Stage | ~Duration |
|---|---|
| Pi boot to systemd `squeakshot-record` ready | 20-30 s |
| First START -> Libav encoder ready on all Pis  | 5-15 s |
| START reply propagating back to controller | < 1 s |

The controller waits up to 60 s for the control port and up to 60 s for the
START reply, so a cold start should not time out as long as the Pis are
booting normally.

For day-to-day recording (Pis already running), each cycle is sub-second.

---

## Files intentionally not committed

- `controller/camera_config.json` (contains real Pi IPs and the `maiya` user)
- `controller/camera_config.json.bak` (auto-rotated backup)
- `controller/logs/` (rotating run log)
- Screenshots of preflight dialogs etc. at repo root (delete or .gitignore)

`controller/camera_config.example.json` IS committed and serves as the template.

---

*Regenerate or amend this file when operational details change.*

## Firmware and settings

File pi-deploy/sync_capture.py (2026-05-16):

#!/usr/bin/env python3
"""
Synchronized Camera Capture Service v9.2.5
Multi-camera star topology: one server, N clients.

Changes from v9.2.4:
- Write the PTS file ourselves via TimestampingFileOutput, a FileOutput subclass
  that calls super().outputframe() first (so video recording is never affected)
  then writes the timestamp to a sidecar .pts as a side effect. picamera2's
  start_encoder(pts=...) kwarg is silently ignored on Pi 5 (libav path doesn't
  honor it), so the .pts files were being skipped even though the kwarg was
  accepted.
- Quiet the "force_key_frame unsupported" log line. The Libav-based encoder
  produces a keyframe on frame 0 automatically, so the warning is just noise.

Changes from v9.2.3:
- Runtime monkey-patch for picamera2 + new python3-av incompatibility on Pi 5.
  picamera2's libav_h264_encoder.py sets frame.pict_type = "I" (string), but
  PyAV >=14 requires an integer/enum. We rewrite _encode at import time to
  use the integer value. This fixes cam2 (and any Pi running libcamera 0.7+
  with the newer PyAV) without requiring apt surgery.
- Realization: on Pi 5 there is no hardware H264 encoder, so picamera2 routes
  H264Encoder and LibavH264Encoder through the same Libav code path.

Changes from v9.2.2:
- Default encoder switched to V4L2 H264Encoder (was Libav). SQUEAKSHOT_PREFER_LIBAV=1
  opts back into Libav. (Largely cosmetic on Pi 5; the real fix is the
  pict_type patch in v9.2.4.)
- stop_recording() sleeps 0.25s before counting the PTS file so picamera2 has
  time to flush.

Changes from v9.2.1:
- Drop custom PTSOutput subclass entirely. (Replaced again in v9.2.5 with a
  safer subclass that does not bypass the parent's outputframe.)

Changes from v9.2:
- Fix ACK race: main select() loop now skips client sockets while the control
  worker is busy.

Changes from v9.1:
- Pi 5 / libcamera compatibility (NoiseReductionModeEnum guard, encode="main")
- PTSOutput bypasses FileOutput.outputframe keyframe gate (fixes 0-byte .h264 on Pi 5)
- create_h264_encoder() prefers LibavH264Encoder (software x264 via PyAV) when available,
  falls back to V4L2 H264Encoder. iperiod from FPS. framerate as Fraction.
- Server uses a worker thread for control commands so wait_until + start_encoder do not
  block Picamera2 servicing. control_busy Event prevents recv() race on control socket.
- Initial STATUS send uses blocking socket to avoid BlockingIOError.
- recv_message timeout raised 0.1 -> 5.0 on control reads.

Changes from v9.0:
- START command parses name=filename pairs (no more positional cam1/cam2 assumption)
- Server sends PING every 10s; clients auto-stop recording on >30s server silence
- Client tracks last_server_msg_time for heartbeat health

Usage:
    Server: python3 sync_capture.py server [--config <path>]
    Client: python3 sync_capture.py client --server-ip <IP> --name <name> [--config <path>]
"""

import argparse
import fractions
import queue
import socket
import select
import time
import threading
import os
import json
from datetime import datetime
from picamera2 import Picamera2
from picamera2.encoders import H264Encoder
from picamera2.outputs import FileOutput
from libcamera import controls
import signal
import sys

# Try to import LibavH264Encoder. On Pi 5 with python3-av installed, this gives
# software x264 via PyAV, which is more reliable than the V4L2 H264Encoder.
try:
    from picamera2.encoders import LibavH264Encoder
    _HAS_LIBAV = True
except Exception:
    LibavH264Encoder = None
    _HAS_LIBAV = False


def _patch_libav_pict_type():
    """Patch picamera2's LibavH264Encoder._encode for newer python3-av.

    On Pi 5 with libcamera 0.7+ and newer python3-av (av 14+), picamera2's
    libav_h264_encoder.py contains:

        frame.pict_type = "I"

    Newer PyAV requires an enum or integer for pict_type and raises
    'TypeError: an integer is required' on the string form. The Pi 5 has no
    hardware H264 encoder, so picamera2 routes BOTH H264Encoder and
    LibavH264Encoder through this same Libav-based code path on newer
    versions, meaning we cannot avoid this bug by encoder selection alone.

    This function rewrites _encode at import time, substituting the integer
    value for the string. Logs whether the patch was applied so we can verify
    it's running. No-op when picamera2 already has the fix.
    """
    try:
        import inspect, textwrap
        import picamera2.encoders.libav_h264_encoder as _libav_mod
        cls = _libav_mod.LibavH264Encoder
        src = textwrap.dedent(inspect.getsource(cls._encode))
        if 'pict_type = "I"' not in src:
            print("[patch] LibavH264Encoder._encode already correct, no patch needed")
            return False
        # av.video.frame.PictureType.I has integer value 1 (h264/ffmpeg standard).
        # Use the integer directly so we do not require importing the enum here.
        new_src = src.replace('pict_type = "I"', 'pict_type = 1  # patched for new PyAV')
        local_ns = {}
        exec(new_src, cls._encode.__globals__, local_ns)
        cls._encode = local_ns["_encode"]
        print("[patch] LibavH264Encoder._encode patched for newer python3-av")
        return True
    except Exception as e:
        print(f"[patch] Could not patch LibavH264Encoder: {e}. "
              f"If this Pi has new python3-av, recordings may produce 0-byte files.")
        return False


# Apply the patch unconditionally at startup. Harmless if the bug is not present.
if _HAS_LIBAV:
    _patch_libav_pict_type()

# Network ======================================================================
CLIENT_PORT = 5005
CONTROL_PORT = 5006
SYNC_MARGIN = 3.0
STOP_MARGIN = 2.0

# Heartbeat ====================================================================
HEARTBEAT_INTERVAL = 10.0     # server sends PING every N seconds
HEARTBEAT_TIMEOUT = 30.0      # client auto-stops if no msg from server for N seconds

# Defaults =====================================================================
DEFAULTS = {
    "output_width": 1536, "output_height": 864,
    "sensor_width": 2304, "sensor_height": 1296,
    "framerate": 56, "bitrate_mbps": 25,
    "video_dir": os.path.expanduser("~/camera_videos"),
}


def load_settings(config_path=None):
    if config_path is None:
        script_dir = os.path.dirname(os.path.abspath(__file__))
        config_path = os.path.join(script_dir, "camera_settings.json")
    settings = DEFAULTS.copy()
    if os.path.exists(config_path):
        try:
            with open(config_path, "r") as f:
                loaded = json.load(f)
            settings.update(loaded)
            print(f"  Loaded settings from {config_path}")
        except Exception as e:
            print(f"  Warning: could not load {config_path}: {e}")
    else:
        print(f"  No settings file at {config_path}, using defaults")
    if "video_dir" in settings:
        settings["video_dir"] = os.path.expanduser(settings["video_dir"])
    return settings


# Global state =================================================================
running = True
picam2 = None
encoder = None
recording = False
current_output = None
SETTINGS = None


def signal_handler(sig, frame):
    global running
    print("\nShutting down service...")
    running = False
    sys.exit(0)


signal.signal(signal.SIGINT, signal_handler)
signal.signal(signal.SIGTERM, signal_handler)


# Recording state ==============================================================
# Earlier versions tried two approaches that did not work on Pi 5:
#   1. Subclass FileOutput and call FileOutput._write directly, bypassing the
#      parent's outputframe(). This broke recording (0-byte .h264 files).
#   2. Pass pts=<path> to picam2.start_encoder(). The signature accepts it,
#      but picamera2's libav-based encoder path on Pi 5 silently ignores it,
#      so no .pts file gets written.
# This version uses TimestampingFileOutput, which:
#   - Forwards the frame to super().outputframe() FIRST (recording works)
#   - Writes the timestamp to a side-channel file AFTER as a side effect
#   - Uses *args/**kwargs to be robust to outputframe signature differences
#     across picamera2 versions
current_pts_path = None


class TimestampingFileOutput(FileOutput):
    """FileOutput that also records per-frame timestamps to a sidecar .pts file.

    The H264 video write goes through the unmodified parent FileOutput, so this
    subclass cannot break video recording (the v9.2.1 lesson). The timestamp
    write happens AFTER the parent's outputframe returns and any failure there
    is non-fatal."""

    def __init__(self, video_path, pts_path):
        super().__init__(video_path)
        self._pts_path = pts_path
        self._pts_file = None
        self._last_ts = None
        self._pts_count = 0

    def start(self):
        super().start()
        try:
            self._pts_file = open(self._pts_path, "w")
        except Exception as e:
            print(f"  WARNING: could not open PTS file {self._pts_path}: {e}")
            self._pts_file = None

    def outputframe(self, frame, *args, **kwargs):
        # Always call the parent FIRST so video recording is never affected.
        super().outputframe(frame, *args, **kwargs)
        # Now extract timestamp without assuming a specific signature.
        timestamp = kwargs.get("timestamp")
        if timestamp is None and len(args) >= 2:
            # Conventional positional order: (frame, keyframe, timestamp, ...)
            timestamp = args[1]
        if timestamp is None or self._pts_file is None:
            return
        # An I-frame is often emitted as multiple H264 packets (SPS, PPS, IDR)
        # with the same timestamp. Dedupe so the PTS file has one line per frame.
        if timestamp == self._last_ts:
            return
        self._last_ts = timestamp
        try:
            self._pts_file.write(f"{int(timestamp)}\n")
            self._pts_count += 1
        except Exception:
            pass

    def stop(self):
        super().stop()
        if self._pts_file is not None:
            try:
                self._pts_file.flush()
                self._pts_file.close()
            except Exception:
                pass
            self._pts_file = None

    @property
    def frame_count(self):
        return self._pts_count


# Camera =======================================================================
def setup_camera():
    global picam2
    out_w = SETTINGS["output_width"]
    out_h = SETTINGS["output_height"]
    sensor_w = SETTINGS["sensor_width"]
    sensor_h = SETTINGS["sensor_height"]
    fps = SETTINGS["framerate"]
    frame_duration = int(1_000_000 / fps)

    print("Initializing camera...")
    picam2 = Picamera2()
    props = picam2.camera_properties
    print(f"  Model: {props.get('Model', 'Unknown')}")

    # NoiseReductionModeEnum may not exist on some libcamera builds (Pi 5 / newer);
    # guard so we do not crash camera init if it is missing.
    _nrm = getattr(controls, "NoiseReductionModeEnum", None)
    _ctrls = {
        "FrameDurationLimits": (frame_duration, frame_duration),
    }
    if _nrm is not None:
        _ctrls["NoiseReductionMode"] = _nrm.Fast

    config = picam2.create_video_configuration(
        main={"size": (out_w, out_h), "format": "YUV420"},
        raw={"size": (sensor_w, sensor_h)},
        controls=_ctrls,
        buffer_count=6,
        encode="main",  # explicitly target the main YUV stream for H264 encoding
    )
    picam2.configure(config)
    try:
        if "AfMode" in picam2.camera_controls:
            picam2.set_controls({"AfMode": controls.AfModeEnum.Manual, "LensPosition": 0.5})
            print("  Focus: Manual (hyperfocal)")
        else:
            print("  Focus: Fixed (no AF motor)")
    except Exception as e:
        print(f"  Focus: Could not configure ({e})")

    print(f"  Sensor mode: {sensor_w}x{sensor_h} (full FOV)")
    print(f"  Output:      {out_w}x{out_h} @ {fps} fps")
    print(f"  Bitrate:     {SETTINGS['bitrate_mbps']} Mbps")
    picam2.start()
    print("  Camera started")


def wait_until(target_time):
    while time.time() < target_time:
        remaining = target_time - time.time()
        if remaining > 0.1:
            time.sleep(0.05)
        elif remaining > 0.01:
            time.sleep(0.001)


def create_h264_encoder(bitrate_bps, fps_num):
    """Create an H264 encoder. Defaults to V4L2 H264Encoder, which works
    reliably across our Pi 5 cameras (verified empirically).

    LibavH264Encoder is available as opt-in via SQUEAKSHOT_PREFER_LIBAV=1, but
    on newer python3-av (e.g. the version that ships with libcamera 0.7+),
    picamera2's libav_h264_encoder.py raises TypeError when it sets
    frame.pict_type = "I" (newer PyAV requires an enum/int, not a string).
    This is an upstream picamera2/PyAV mismatch we cannot fix from this script.

    iperiod set from configured FPS (a keyframe per ~1 second of footage)."""
    iperiod = max(2, int(fps_num))
    prefer_libav = os.environ.get("SQUEAKSHOT_PREFER_LIBAV", "0") == "1"
    if prefer_libav and _HAS_LIBAV:
        framerate = fractions.Fraction(int(fps_num), 1)
        print(f"  Encoder: LibavH264Encoder (PyAV, iperiod={iperiod}, fps={fps_num})")
        return LibavH264Encoder(
            bitrate=bitrate_bps, framerate=framerate, iperiod=iperiod
        )
    print(f"  Encoder: H264Encoder (V4L2, iperiod={iperiod}, fps={fps_num})")
    return H264Encoder(bitrate=bitrate_bps, iperiod=iperiod)


def _count_pts_frames(pts_path):
    """Count frames by counting lines in the PTS file picamera2 wrote."""
    if not pts_path or not os.path.exists(pts_path):
        return 0
    try:
        with open(pts_path) as f:
            return sum(1 for _ in f)
    except Exception:
        return 0


def start_recording(filename):
    global picam2, encoder, recording, current_output, current_pts_path
    os.makedirs(SETTINGS["video_dir"], exist_ok=True)
    video_path = os.path.join(SETTINGS["video_dir"], f"{filename}.h264")
    pts_path = os.path.join(SETTINGS["video_dir"], f"{filename}.pts")
    print(f"Starting recording: {filename}")
    encoder = create_h264_encoder(
        bitrate_bps=SETTINGS["bitrate_mbps"] * 1_000_000,
        fps_num=SETTINGS["framerate"],
    )
    # TimestampingFileOutput wraps stock FileOutput and writes the PTS file as
    # a side effect. The pts= kwarg on start_encoder is silently ignored by
    # picamera2's libav path on Pi 5, so we cannot rely on it.
    current_output = TimestampingFileOutput(video_path, pts_path)
    current_pts_path = pts_path
    picam2.start_encoder(encoder, current_output)
    # Nudge an IDR frame so the first NAL is a keyframe and downstream decoders
    # (ffmpeg, players) can lock on immediately. Wrapped because force_key_frame
    # is not present on every encoder build (the libav-based path lacks it).
    try:
        encoder.force_key_frame()
    except Exception:
        pass  # silently skip; libav encoder produces a keyframe on frame 0 anyway
    recording = True
    print(f"  Recording to: {video_path}")
    return True


def stop_recording():
    global picam2, encoder, recording, current_output, current_pts_path
    if not recording:
        return 0
    # picam2.stop_encoder() can raise RuntimeError("Encoder already stopped")
    # if the encoder errored internally during start_encoder. Don't let that
    # leak up and crash the whole service.
    try:
        picam2.stop_encoder()
    except RuntimeError as e:
        print(f"  stop_encoder warning: {e}")
    except Exception as e:
        print(f"  stop_encoder unexpected error: {e}")
    # Give picamera2 a moment to flush the PTS file. Without this we sometimes
    # read 0 frames even when the .h264 has real data.
    time.sleep(0.25)
    frame_count = _count_pts_frames(current_pts_path)
    recording = False
    encoder = None
    current_output = None
    current_pts_path = None
    print(f"  Recording stopped. Frames: {frame_count}")
    return frame_count


# Length-prefixed protocol =====================================================
def send_message(sock, message):
    data = message.encode("utf-8")
    sock.sendall(len(data).to_bytes(4, "big") + data)


def recv_message(sock, timeout=None):
    sock.settimeout(timeout)
    try:
        length_data = b""
        while len(length_data) < 4:
            chunk = sock.recv(4 - len(length_data))
            if not chunk:
                return None
            length_data += chunk
        length = int.from_bytes(length_data, "big")
        if length <= 0 or length > 10000:
            return None
        data = b""
        while len(data) < length:
            chunk = sock.recv(length - len(data))
            if not chunk:
                return None
            data += chunk
        return data.decode("utf-8")
    except socket.timeout:
        return None
    except Exception:
        return None


# Server =======================================================================
class ClientConnection:
    def __init__(self, sock, addr, name="unknown"):
        self.sock = sock
        self.addr = addr
        self.name = name

    def fileno(self):
        return self.sock.fileno()


def _parse_start_cmd(parts):
    """Parse a START command and return {name: filename, ...} plus the server's
    own name/filename. Accepts the new name=filename format only."""
    pairs = {}
    for token in parts[1:]:
        if "=" not in token:
            return None
        name, fn = token.split("=", 1)
        pairs[name] = fn
    return pairs
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

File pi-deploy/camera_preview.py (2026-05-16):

#!/usr/bin/env python3
"""
Camera Preview Server
Runs on a Raspberry Pi to stream a low-res MJPEG preview.
Mutually exclusive with sync_capture (they share the camera).

Usage:
    python3 camera_preview.py
    
Access stream at: http://<pi-ip>:8080/stream.mjpg
"""

import io
import json
import os
import sys
import traceback
from http.server import BaseHTTPRequestHandler, HTTPServer
from threading import Condition

from picamera2 import Picamera2
from picamera2.encoders import JpegEncoder
from picamera2.outputs import FileOutput

# Preview settings (fixed: independent of recording resolution)
PREVIEW_WIDTH = 640
PREVIEW_HEIGHT = 360
PREVIEW_FPS = 15
PORT = 8080


class StreamingOutput(io.BufferedIOBase):
    def __init__(self):
        self.frame = None
        self.condition = Condition()

    def write(self, buf):
        with self.condition:
            self.frame = buf
            self.condition.notify_all()


class StreamingHandler(BaseHTTPRequestHandler):
    def do_GET(self):
        if self.path == "/":
            self.send_response(200)
            self.send_header("Content-type", "text/html")
            self.send_header("Access-Control-Allow-Origin", "*")
            self.end_headers()
            html = (
                "<html><body><h1>SqueakShot Preview</h1>"
                '<img src="/stream.mjpg" width="640" height="360" /></body></html>'
            )
            self.wfile.write(html.encode())
        elif self.path == "/stream.mjpg":
            self.send_response(200)
            self.send_header("Age", 0)
            self.send_header("Cache-Control", "no-cache, private")
            self.send_header("Pragma", "no-cache")
            self.send_header(
                "Content-Type", "multipart/x-mixed-replace; boundary=FRAME"
            )
            self.send_header("Access-Control-Allow-Origin", "*")
            self.end_headers()
            try:
                while True:
                    with output.condition:
                        output.condition.wait()
                        frame = output.frame
                    if frame is None:
                        continue
                    self.wfile.write(b"--FRAME\r\n")
                    self.send_header("Content-Type", "image/jpeg")
                    self.send_header("Content-Length", len(frame))
                    self.end_headers()
                    self.wfile.write(frame)
                    self.wfile.write(b"\r\n")
            except Exception as e:
                print(f"Removed streaming client {self.client_address}: {e}")
        elif self.path == "/snapshot.jpg":
            self.send_response(200)
            self.send_header("Content-type", "image/jpeg")
            self.send_header("Access-Control-Allow-Origin", "*")
            self.end_headers()
            with output.condition:
                output.condition.wait()
                frame = output.frame
            if frame is not None:
                self.wfile.write(frame)
        elif self.path == "/status":
            self.send_response(200)
            self.send_header("Content-type", "text/plain")
            self.send_header("Access-Control-Allow-Origin", "*")
            self.end_headers()
            self.wfile.write(
                f"OK {PREVIEW_WIDTH}x{PREVIEW_HEIGHT}@{PREVIEW_FPS}".encode()
            )
        else:
            self.send_error(404)
            self.end_headers()

    def log_message(self, format, *args):
        return

    def do_OPTIONS(self):
        self.send_response(200)
        self.send_header("Access-Control-Allow-Origin", "*")
        self.send_header("Access-Control-Allow-Methods", "GET, OPTIONS")
        self.send_header("Access-Control-Allow-Headers", "*")
        self.end_headers()


class StreamingServer(HTTPServer):
    allow_reuse_address = True


def main():
    global output
    print(f"Starting preview server on port {PORT}")
    print(f"  Resolution: {PREVIEW_WIDTH}x{PREVIEW_HEIGHT} @ {PREVIEW_FPS}fps")

    try:
        picam2 = Picamera2()
        config = picam2.create_video_configuration(
            main={"size": (PREVIEW_WIDTH, PREVIEW_HEIGHT), "format": "RGB888"},
            controls={"FrameRate": PREVIEW_FPS},
        )
        picam2.configure(config)
        output = StreamingOutput()
        picam2.start_recording(JpegEncoder(), FileOutput(output))
        print(f"Preview live at http://<this-pi-ip>:{PORT}/stream.mjpg")
        print("Press Ctrl+C to stop\n")
        server = StreamingServer(("", PORT), StreamingHandler)
        server.serve_forever()
    except KeyboardInterrupt:
        print("\nShutting down...")
    except Exception as e:
        print(f"\nERROR: {e}")
        print("\nIf camera is busy, stop the recording service first:")
        print("  sudo systemctl stop squeakshot-record")
        traceback.print_exc()
        sys.exit(1)
    finally:
        try:
            picam2.stop_recording()
        except Exception:
            pass


if __name__ == "__main__":
    main()

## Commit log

2026-05-15 v9.2.5: PTS recording works on Pi 5, libav PyAV pict_type patch, encoder fixes
    [camera_preview.py, sync_capture.py]
2026-05-16 Fix capture/controller bugs, add settings deploy, conda install, refresh docs
    Bug fixes:
    - sync_capture.py: remove duplicated client STOP handler block
    - camera_controller.py: shlex-quote the SSH delete path (shell injection)
    - guard encode/sync/trim routes against zero configured cameras
    - sync writes the .pts sidecar for the contiguous range actually in the MP4
    - camera_preview.py: don't serve a None first frame
    Controller / GUI:
    - New "Deploy to Pis" button + /api/deploy_settings: pushes camera
    settings to every Pi and restarts the record service where active
    - Inline pre-flight results, undeployed-changes badge, button loading
    states, per-camera preview reload
    Install:
    - environmen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
    [camera_preview.py, sync_capture.py]
2026-07-24 Add hardware build guide (BOM, dimensions, assembly, wiring) and CAD/print files
    Documents the physical three-camera recording rig that the software drives:
    - BUILD.md: bill of materials, dimensions, 3D-printed parts, assembly, wiring
    - hardware/: print-ready .3mf and editable .f3d sources (Git LFS) + file index
    - docs/images/: full-setup and Pi-case renders
    - README: link the build guide from Hardware, extend the Files tree
    [Buttons.3mf, Buttons.f3d, Case_Supports.3mf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]
2026-07-24 Clarify Pi-case CAD file paths in hardware index
